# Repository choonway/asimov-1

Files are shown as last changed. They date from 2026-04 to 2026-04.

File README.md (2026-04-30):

# Asimov v1: Open-Source Humanoid Robot




Asimov is an open-source humanoid robot that you can build, train and customize.

Asimov v1
<p align="center">
  <a href="https://asimov.inc">Website</a> ·
  <a href="https://manual.asimov.inc">Manual</a> ·
  <a href="https://asimov.inc/diy-kit">DIY Kit</a> ·
  <a href="https://static.asimov.inc/asimov/v1/asimov-v1-20260420.html">3D Model</a> ·
  <a href="https://discord.gg/HzDfGN7kUw">Discord</a> ·
  <a href="https://x.com/asimovinc">X</a> ·
  <a href="https://forum.menlo.ai">Forum</a>
</p>

Asimov v1 is a 1.2 m, 35 kg biped with 25 actuated degrees of freedom. This repository contains the mechanical CAD, electrical CAD, simulation model, and onboard software to build, simulate, and customize Asimov v1.

---

## Specifications

| Spec | Value |
|---|---|
| Height | 1.2 m |
| Weight | 35 kg |
| Degrees of Freedom | 25 actuated + 2 passive |
| Legs | 6 DOF x 2 + toe x 2 |
| Arms | 5 DOF x 2 (shoulder pitch/roll/yaw, elbow, wrist yaw) |
| Torso | 1 DOF waist yaw, 10 W 4 ohm speaker, 6 DOF IMU |
| Head | 2 DOF neck (neck yaw, neck pitch), Quad microphone array, 2MP monocular camera |
| CAN Bus | 5 @ 1Mbps + 1 @ 500kbps |
| Onboard Compute | Raspberry Pi 5 (media + network) + Radxa CM5 (motion control) |
| Structural Materials | 7075 aluminium, MJF PA12 nylon |

| Activity | Load |
|---|---|
| Squat | 5 kg |
| Bicep curl | 15 kg each arm |
| Lateral raise | 18 kg each arm |

---

## Build your own Asimov

> [!TIP]
> **Option 1: DIY Kit:** Everything you need to build Asimov v1, unassembled. $499 deposit to reserve. $15,000 target price. Ships summer 2026. [Pre-order →](https://asimov.inc/diy-kit)

> [!NOTE]
> **Option 2: Self-source:** Pull the [BOM](https://manual.asimov.inc/v1/bom) and fabricate everything yourself. [Assembly Manual →](https://manual.asimov.inc)

### DIY Kit

| Category | Included | Not Included |
|---|---|---|
| Hardware | All BOM components (unassembled), power supply & cabling, spare parts | Tools, hands |
| Compute | RPi edge board, motion control board, network board, power distribution board | 4G/5G modules |
| Sensors | Monocular camera, IMUs, mic, speaker, motor joint states | Lidar, 360 cam |
| Safety | Wireless E-Stop, safety guidelines | Battery |
| Docs | Quick start guide, manual, DIY build videos | — |

**[Pre-order the Asimov v1 DIY Kit →](https://asimov.inc/diy-kit)**

### Self-source

Pull the [BOM](https://manual.asimov.inc/v1/bom), source the parts, fabricate what needs fabricating.

**[Assembly Manual →](https://manual.asimov.inc)**

---

## Roadmap

| Status | Item |
|---|---|
| ✅ | Mechanical CAD — 7 subassemblies |
| ✅ | MuJoCo simulation model |
| ✅ | Electrical wiring harness |
| ✅ | Electrical schematics & PCB files |
| 🔜 | Asimov API |
| 🔜 | Locomotion policy |
| 🔜 | Mobile app |

---

## Work with us

- **Build questions?**: Ask in the [forum](https://forum.menlo.ai) or open a [GitHub Issue](https://github.com/asimovinc/asimov-v1/issues) for bugs and contributions.
- **Deploying Asimov?**: [Talk to us →](mailto:bd@menlo.ai)
- **Supply chain partner?**: If you manufacture actuators, structural components, or electronics and want to be part of the Asimov supply chain, reach out.
[bd@menlo.ai](mailto:bd@menlo.ai)

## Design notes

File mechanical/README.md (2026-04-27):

# Mechanical Design

CAD for all 7 Asimov v1 subassemblies. STEP files, CNC aluminium parts, MJF nylon parts, and off-the-shelf hardware.

## Contents

```
mechanical/ASV1/
├── ASIMOV_V1.STEP          Full robot assembly
├── 100/ - 700/             Subassemblies
│   ├── ASV1_NNN.STEP       Subassembly STEP
│   └── FABRICATION/
│       ├── ALU_7075/       CNC-machined aluminium parts
│       ├── MJF_PA12/       3D-printed nylon parts (HP MJF)
│       └── OFF_THE_SHELF/  Standard hardware
└── NamingConvention.png    Part naming reference
```

**[View the full assembly in your browser →](https://static.asimov.inc/asimov/v1/asimov-v1-20260420.html)**

## Naming Convention

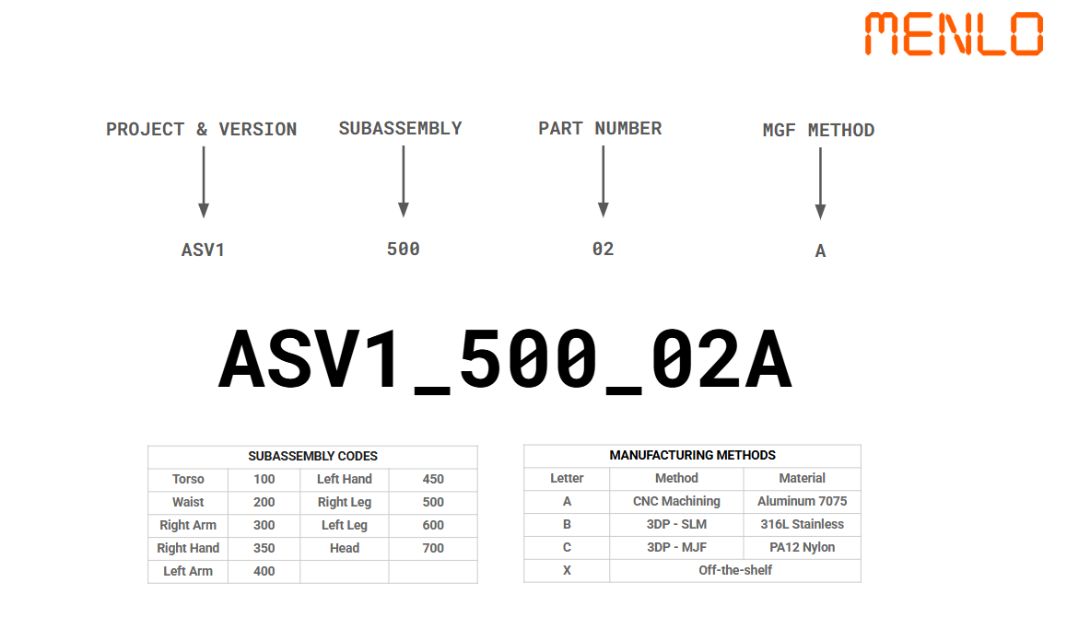
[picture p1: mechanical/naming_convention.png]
Naming Convention


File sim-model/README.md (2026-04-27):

# Simulation Model

MuJoCo model for Asimov v1. 25 actuated joints, 28 link meshes, friction-tuned foot contacts. Built for locomotion policy training and hardware-in-the-loop testing.

## Contents

```
sim-model/
├── xmls/asimov.xml     Full robot model
└── assets/meshes/      28 STL link meshes
```

## Usage

```bash
python3 -m mujoco.viewer --mjcf=sim-model/xmls/asimov.xml
```

Requires [MuJoCo](https://mujoco.org/) 3.x.

## Resources

- [Locomotion Control guide](https://manual.asimov.inc/v1/locomotion) — policy training, control modes, and hardware-in-the-loop setup
- [Asimov API](https://manual.asimov.inc/v1/api) — deploy policies to the real robot
- [Discord](https://discord.gg/HzDfGN7kUw) — questions and discussion

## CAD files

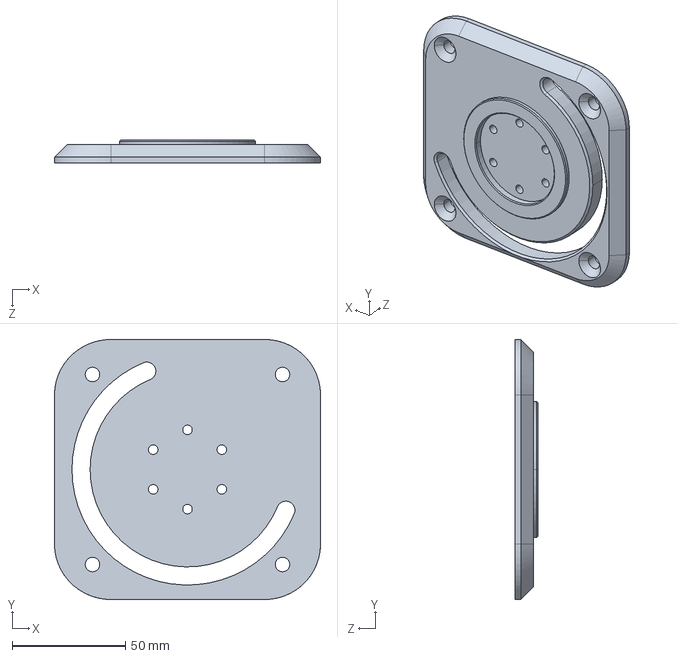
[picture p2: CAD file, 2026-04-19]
mechanical/ASV1/100/FABRICATION/ALU_7075/ASV1_100_02A.STEP
117.4 x 114.8 x 10.0 mm

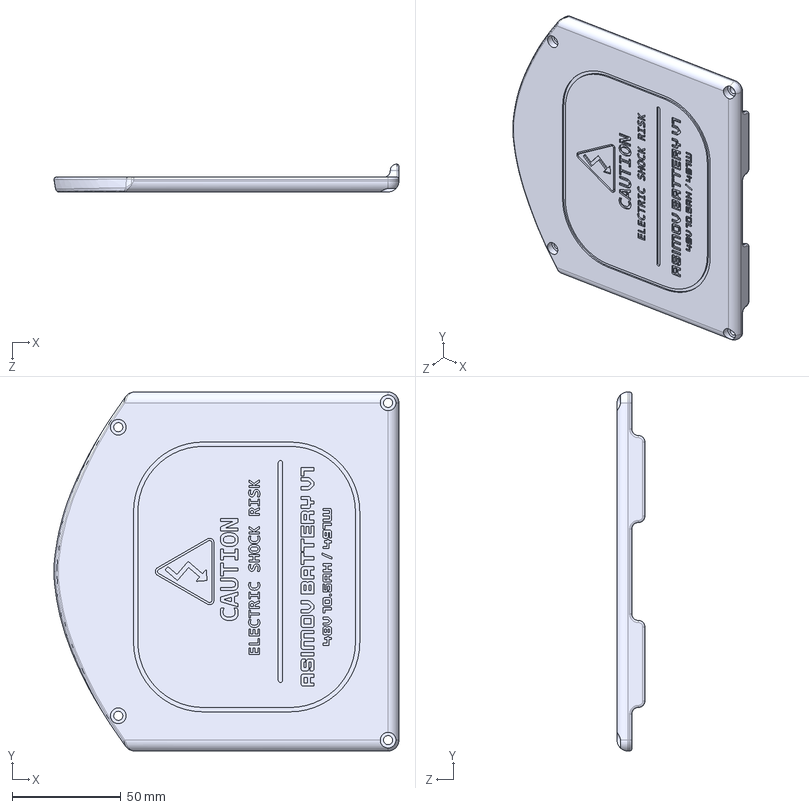
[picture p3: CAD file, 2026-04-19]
mechanical/ASV1/100/FABRICATION/MJF_PA12/ASV1_100_12C.STEP
158.5 x 165.0 x 12.8 mm

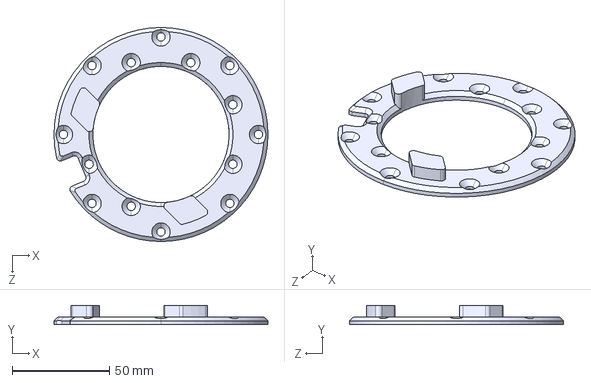
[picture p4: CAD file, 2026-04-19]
mechanical/ASV1/200/FABRICATION/ALU_7075/ASV1_200_02A.STEP
110.0 x 10.0 x 110.0 mm

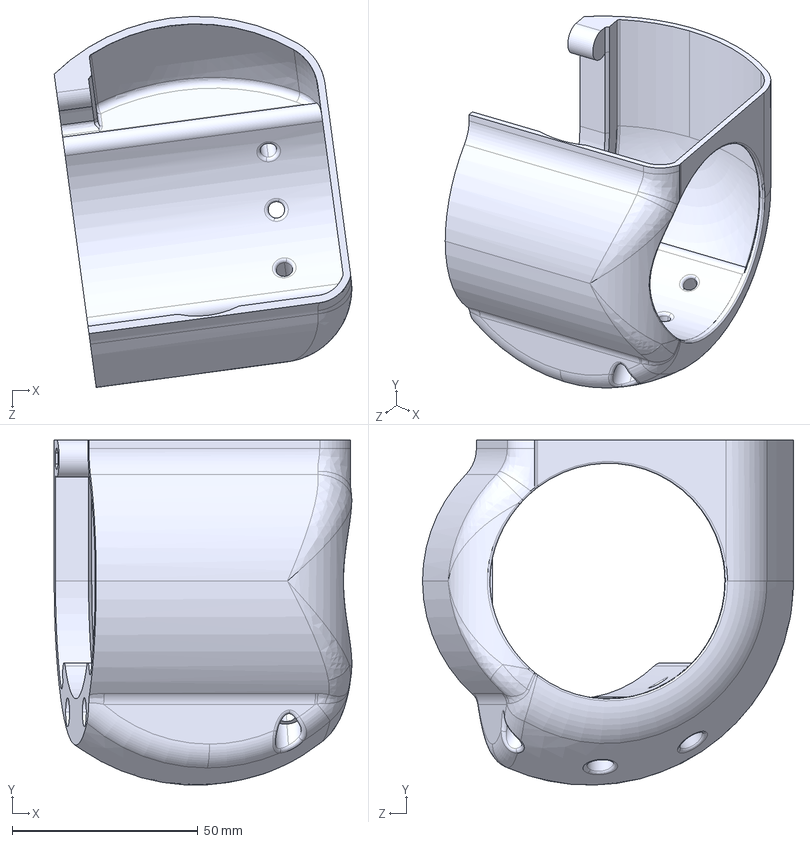
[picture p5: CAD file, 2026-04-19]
mechanical/ASV1/200/FABRICATION/MJF_PA12/ASV1_200_08C.STEP
80.2 x 92.9 x 100.0 mm

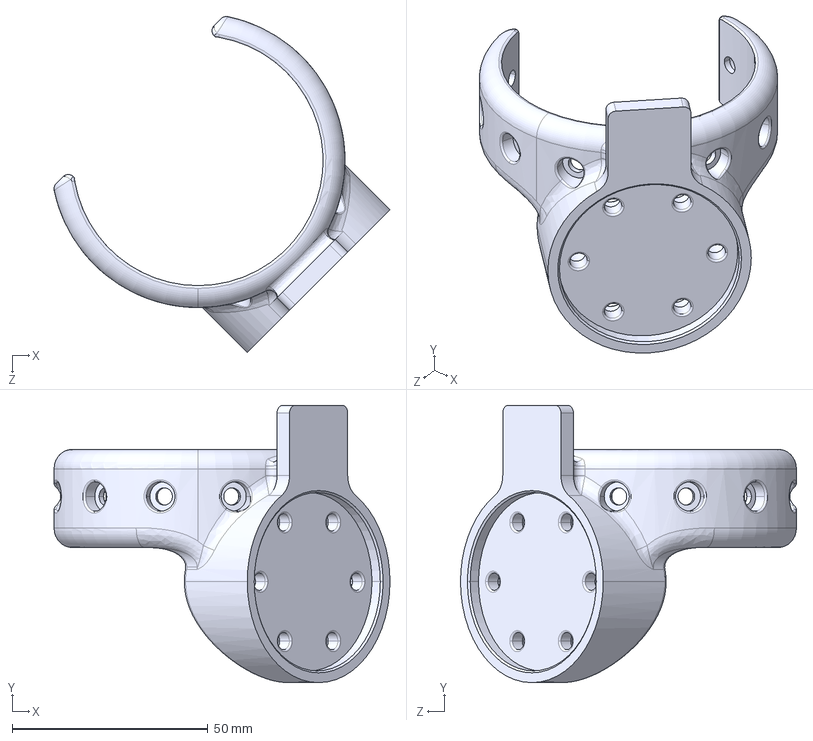
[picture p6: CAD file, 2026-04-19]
mechanical/ASV1/200/FABRICATION/SML_316L/ASV1_200_04B.STEP
85.7 x 70.7 x 85.7 mm

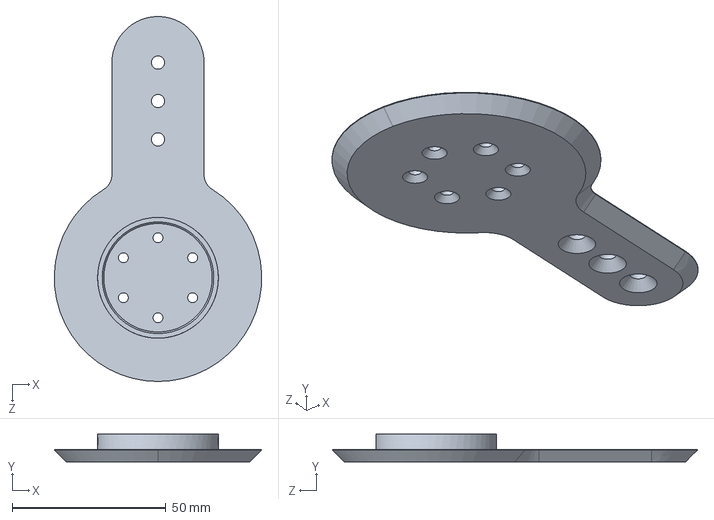
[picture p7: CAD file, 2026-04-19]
mechanical/ASV1/300/FABRICATION/ALU_7075/ASV1_300_10A.STEP
67.5 x 9.00 x 118.8 mm

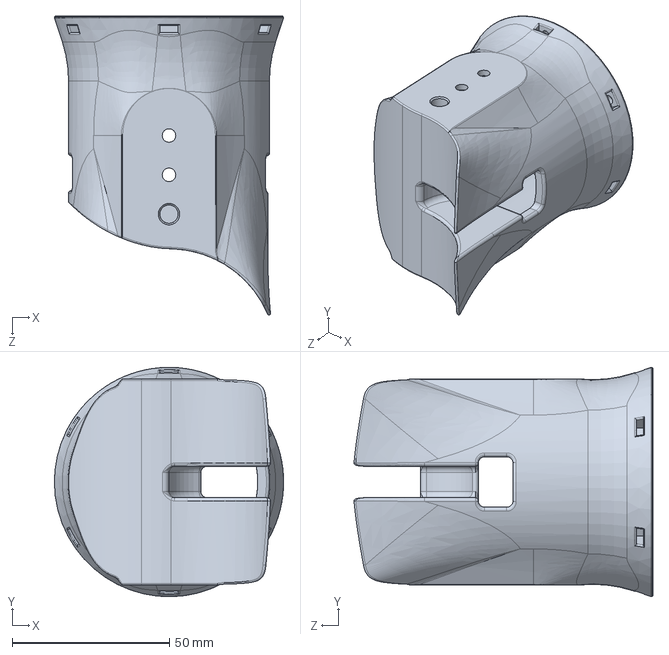
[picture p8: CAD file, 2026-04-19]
mechanical/ASV1/300/FABRICATION/MJF_PA12/ASV1_300_16C.STEP
72.9 x 72.9 x 95.0 mm

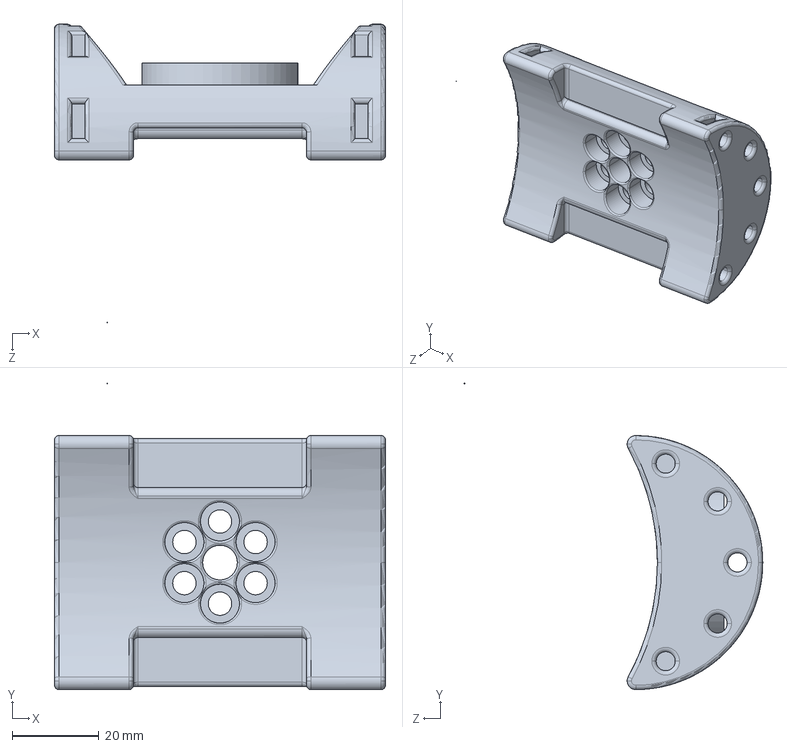
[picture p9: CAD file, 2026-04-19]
mechanical/ASV1/300/FABRICATION/SML_316L/ASV1_300_02B.STEP
76.5 x 70.8 x 69.0 mm

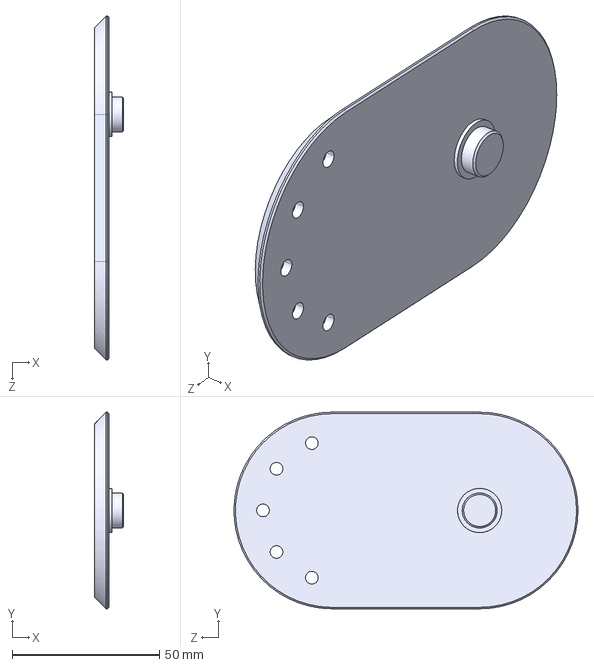
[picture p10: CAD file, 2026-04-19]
mechanical/ASV1/400/FABRICATION/ALU_7075/ASV1_400_04A.STEP
10.0 x 66.7 x 116.7 mm

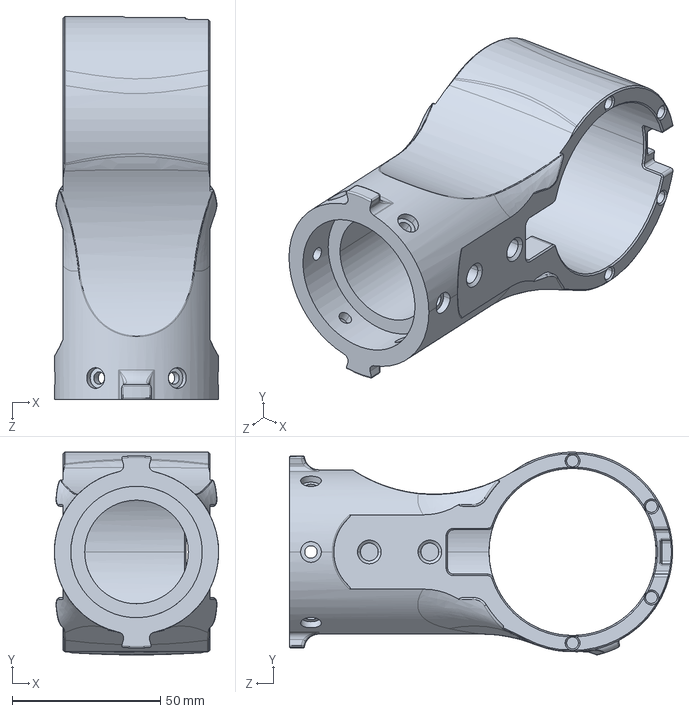
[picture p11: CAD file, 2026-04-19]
mechanical/ASV1/400/FABRICATION/MJF_PA12/ASV1_400_15C.step
55.5 x 68.5 x 129.4 mm

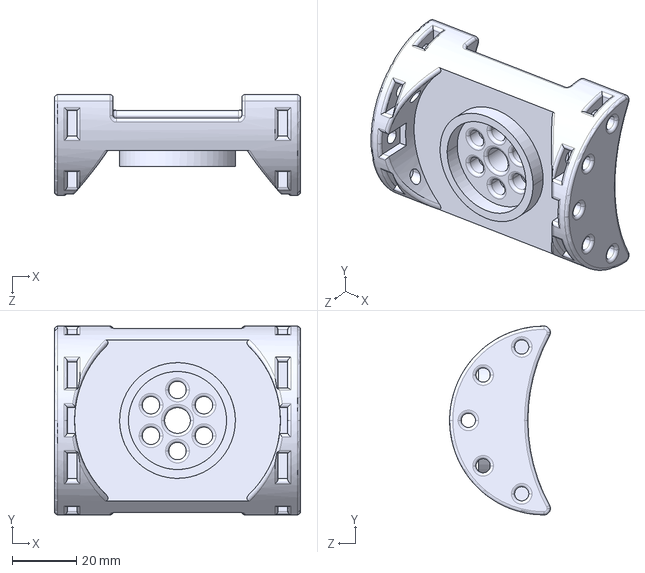
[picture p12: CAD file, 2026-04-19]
mechanical/ASV1/400/FABRICATION/SML_316L/ASV1_400_03B.STEP
76.5 x 58.7 x 31.3 mm

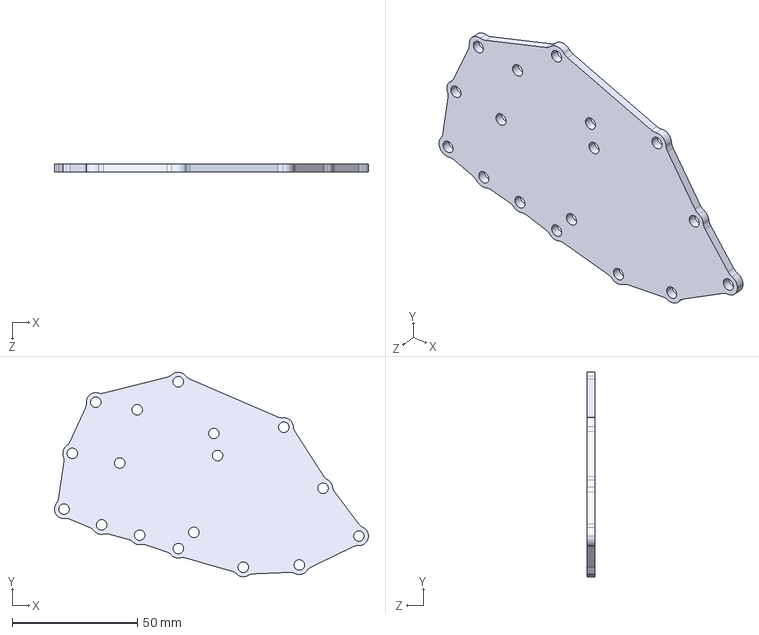
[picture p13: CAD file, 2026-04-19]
mechanical/ASV1/500/FABRICATION/ALU_7075/ASV1_500_36A.STEP
125.1 x 81.5 x 3.00 mm

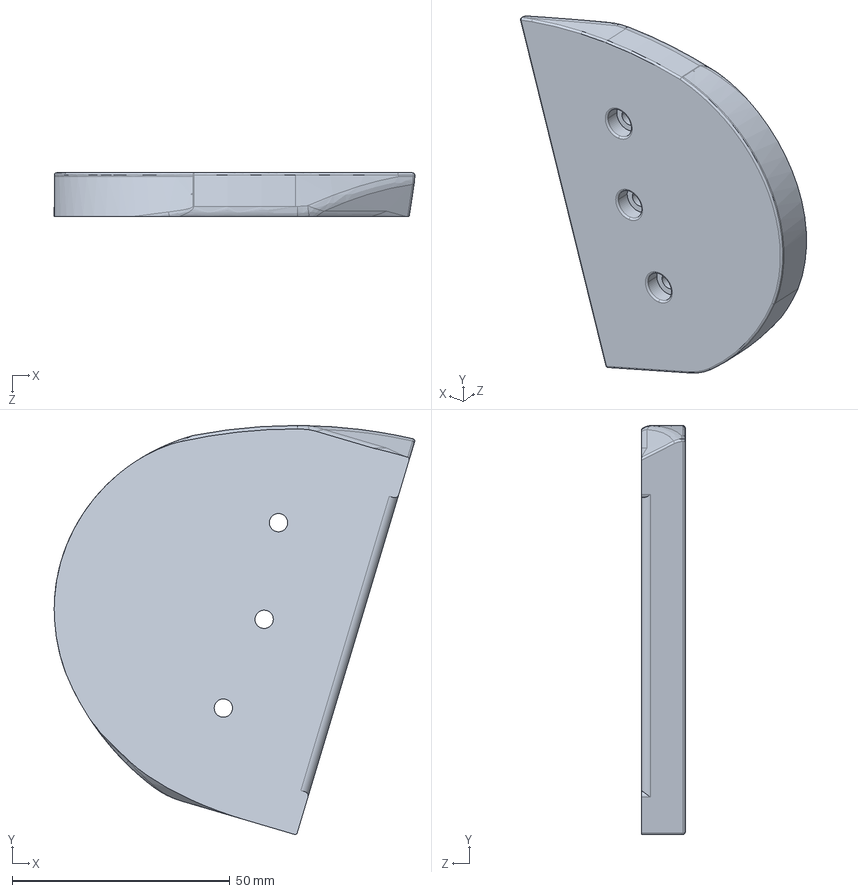
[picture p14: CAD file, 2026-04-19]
mechanical/ASV1/500/FABRICATION/MJF_PA12/ASV1_500_40C.STEP
82.9 x 94.0 x 10.0 mm

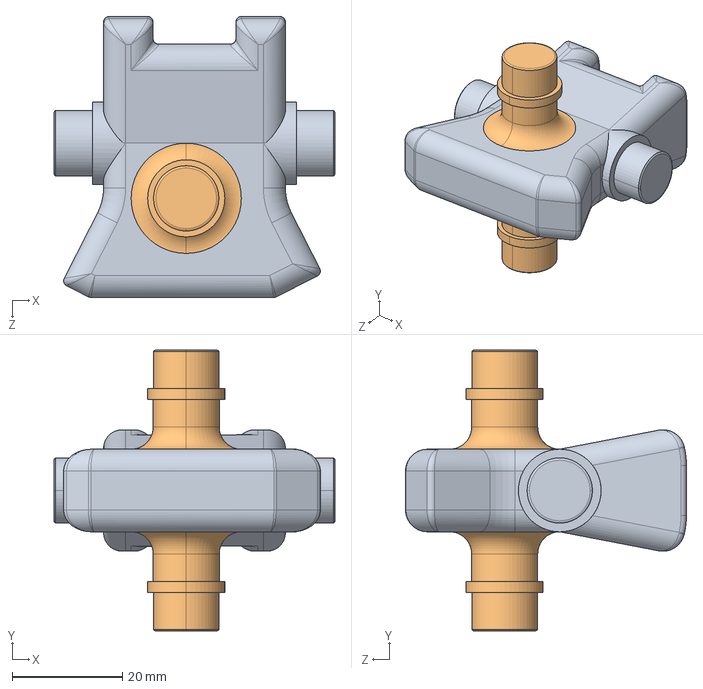
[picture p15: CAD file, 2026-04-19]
mechanical/ASV1/500/FABRICATION/SML_316L/ASV1_500_26B.STEP
51.0 x 51.0 x 51.0 mm

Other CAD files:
mechanical/ASV1/100/ASV1_100.STEP
mechanical/ASV1/600/FABRICATION/ALU_7075/ASV1_600_06A.step.STEP
mechanical/ASV1/600/FABRICATION/MJF_PA12/ASV1_600_14C.step.STEP
mechanical/ASV1/600/FABRICATION/SML_316L/ASV1_600_01B.step.STEP
mechanical/ASV1/100/FABRICATION/ALU_7075/ASV1_100_03A.STEP
mechanical/ASV1/100/FABRICATION/OFF_THE_SHELF/ASV1_100_07X.STEP
mechanical/ASV1/100/FABRICATION/OFF_THE_SHELF/ASV1_100_08X.STEP
mechanical/ASV1/100/FABRICATION/OFF_THE_SHELF/ASV1_100_11X.STEP
mechanical/ASV1/100/FABRICATION/OFF_THE_SHELF/ASV1_100_13X.STEP
mechanical/ASV1/200/FABRICATION/ALU_7075/ASV1_200_03A.STEP
mechanical/ASV1/200/FABRICATION/ALU_7075/ASV1_200_16A.STEP
mechanical/ASV1/200/FABRICATION/MJF_PA12/ASV1_200_01C.STEP
mechanical/ASV1/200/FABRICATION/MJF_PA12/ASV1_200_06C.STEP
mechanical/ASV1/200/FABRICATION/MJF_PA12/ASV1_200_07C.STEP
mechanical/ASV1/200/FABRICATION/MJF_PA12/ASV1_200_09C.STEP
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

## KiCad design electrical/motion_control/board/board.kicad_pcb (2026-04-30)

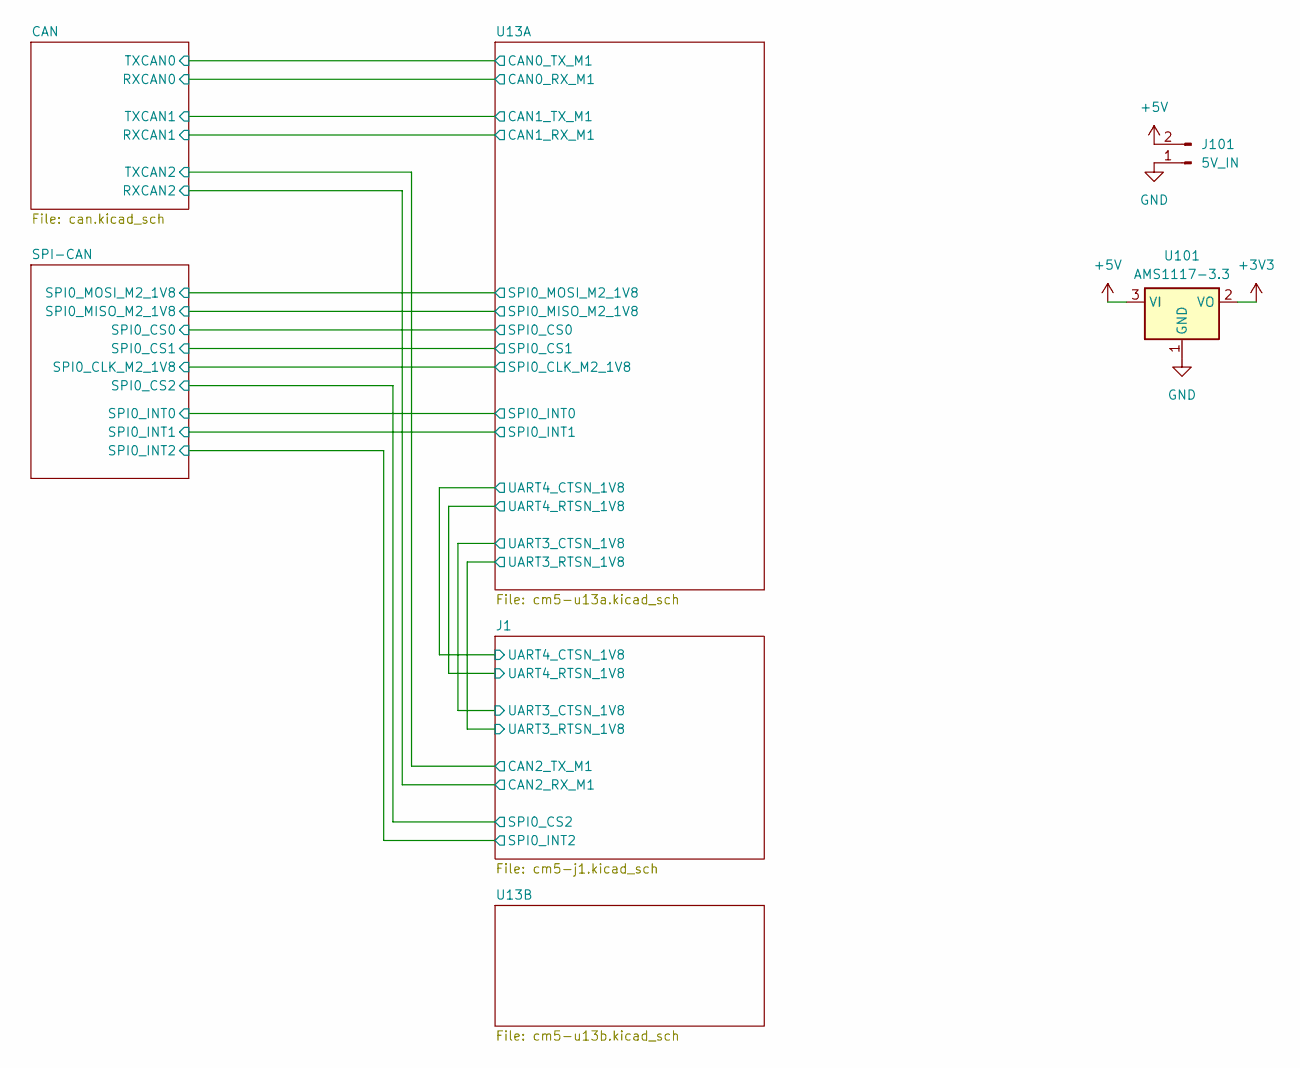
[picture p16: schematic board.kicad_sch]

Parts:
J101: 5V_IN; AMASS_XT30UPB-F_1x02_P5.0mm_Vertical; LCSC C108769
U101: AMS1117-3.3; SOT-223-3_TabPin2; LCSC C6186

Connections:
+3V3: U101.2 (VO); also elsewhere on the board
+5V: J101.2, U101.3 (VI); also elsewhere on the board
GND: J101.1, U101.1 (GND); also elsewhere on the board

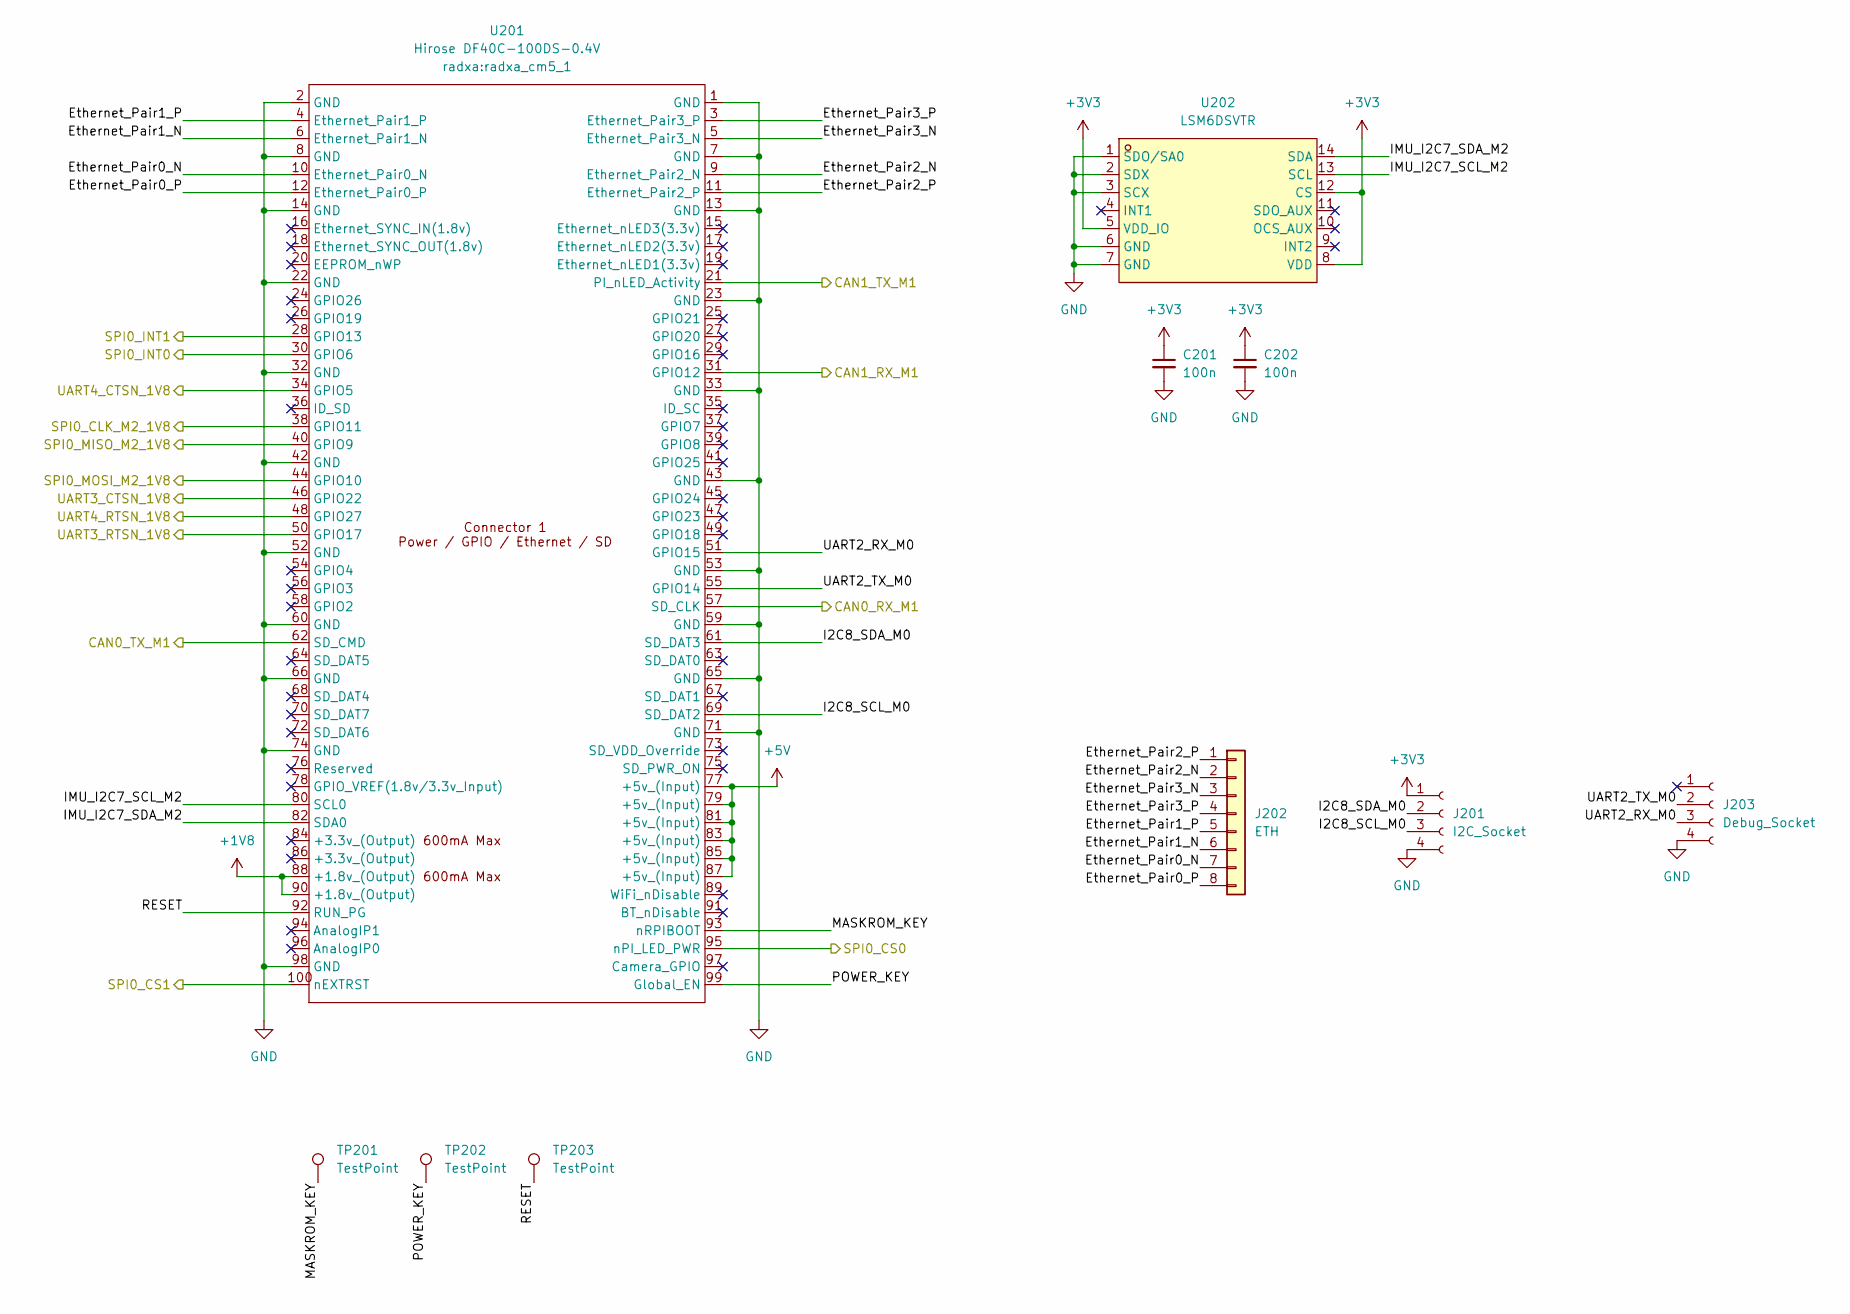
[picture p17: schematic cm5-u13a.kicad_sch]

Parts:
C201, C202: 100n; C_0402_1005Metric; LCSC C77020
J201: I2C_Socket; JST_GH_SM04B-GHS-TB_1x04-1MP_P1.25mm_Horizontal; LCSC C51940118
J202: ETH; JST_GH_BM08B-GHS-TBT_1x08-1MP_P1.25mm_Vertical; LCSC C133062
J203: Debug_Socket; JST_GH_SM04B-GHS-TB_1x04-1MP_P1.25mm_Horizontal; LCSC C51940118
TP201, TP202, TP203: TestPoint; TestPoint_Pad_D1.0mm
U201: Hirose DF40C-100DS-0.4V; radxa_cm5_1; LCSC C597931
U202: LSM6DSVTR; LGA-14_L3.0-W2.5-P0.50-TL; LCSC Part C5267399

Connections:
+1V8: U201.88 (+1.8v_(Output)), U201.90 (+1.8v_(Output)); also elsewhere on the board
+3V3: C201.1, C202.1, J201.1, U202.5 (VDD_IO), U202.8 (VDD), U202.12 (CS); also elsewhere on the board
+5V: U201.77 (+5v_(Input)), U201.79 (+5v_(Input)), U201.81 (+5v_(Input)), U201.83 (+5v_(Input)), U201.85 (+5v_(Input)), U201.87 (+5v_(Input)); also elsewhere on the board
/CAN/RXCAN0: U201.57 (SD_CLK); also elsewhere on the board
/CAN/RXCAN1: U201.31 (GPIO12); also elsewhere on the board
/CAN/TXCAN0: U201.62 (SD_CMD); also elsewhere on the board
/CAN/TXCAN1: U201.21 (PI_nLED_Activity); also elsewhere on the board
/J1/UART3_CTSN_1V8: U201.46 (GPIO22); also elsewhere on the board
/J1/UART3_RTSN_1V8: U201.50 (GPIO17); also elsewhere on the board
/J1/UART4_CTSN_1V8: U201.34 (GPIO5); also elsewhere on the board
/J1/UART4_RTSN_1V8: U201.48 (GPIO27); also elsewhere on the board
/SPI-CAN/SPI0_CLK_M2_1V8: U201.38 (GPIO11); also elsewhere on the board
/SPI-CAN/SPI0_CS0: U201.95 (nPI_LED_PWR); also elsewhere on the board
/SPI-CAN/SPI0_CS1: U201.100 (nEXTRST); also elsewhere on the board
/SPI-CAN/SPI0_INT0: U201.30 (GPIO6); also elsewhere on the board
/SPI-CAN/SPI0_INT1: U201.28 (GPIO13); also elsewhere on the board
/SPI-CAN/SPI0_MISO_M2_1V8: U201.40 (GPIO9); also elsewhere on the board
/SPI-CAN/SPI0_MOSI_M2_1V8: U201.44 (GPIO10); also elsewhere on the board
/U13A/Ethernet_Pair0_N: J202.7, U201.10 (Ethernet_Pair0_N)
/U13A/Ethernet_Pair0_P: J202.8, U201.12 (Ethernet_Pair0_P)
/U13A/Ethernet_Pair1_N: J202.6, U201.6 (Ethernet_Pair1_N)
/U13A/Ethernet_Pair1_P: J202.5, U201.4 (Ethernet_Pair1_P)
/U13A/Ethernet_Pair2_N: J202.2, U201.9 (Ethernet_Pair2_N)
/U13A/Ethernet_Pair2_P: J202.1, U201.11 (Ethernet_Pair2_P)
/U13A/Ethernet_Pair3_N: J202.3, U201.5 (Ethernet_Pair3_N)
/U13A/Ethernet_Pair3_P: J202.4, U201.3 (Ethernet_Pair3_P)
/U13A/I2C8_SCL_M0: J201.3, U201.69 (SD_DAT2)
/U13A/I2C8_SDA_M0: J201.2, U201.61 (SD_DAT3)
/U13A/IMU_I2C7_SCL_M2: U201.80 (SCL0), U202.13 (SCL)
/U13A/IMU_I2C7_SDA_M2: U201.82 (SDA0), U202.14 (SDA)
/U13A/MASKROM_KEY: TP201.1, U201.93 (nRPIBOOT)
/U13A/POWER_KEY: TP202.1, U201.99 (Global_EN)
/U13A/RESET: TP203.1, U201.92 (RUN_PG)
/U13A/UART2_RX_M0: J203.3, U201.51 (GPIO15)
/U13A/UART2_TX_M0: J203.2, U201.55 (GPIO14)
GND: C201.2, C202.2, J201.4, J203.4, U201.1 (GND), U201.2 (GND), U201.7 (GND), U201.8 (GND), U201.13 (GND), U201.14 (GND), U201.22 (GND), U201.23 (GND), U201.32 (GND), U201.33 (GND), U201.42 (GND), U201.43 (GND), U201.52 (GND), U201.53 (GND), U201.59 (GND), U201.60 (GND), U201.65 (GND), U201.66 (GND), U201.71 (GND), U201.74 (GND), U201.98 (GND), U202.1 (SDO/SA0), U202.2 (SDX), U202.3 (SCX), U202.6 (GND), U202.7 (GND); also elsewhere on the board

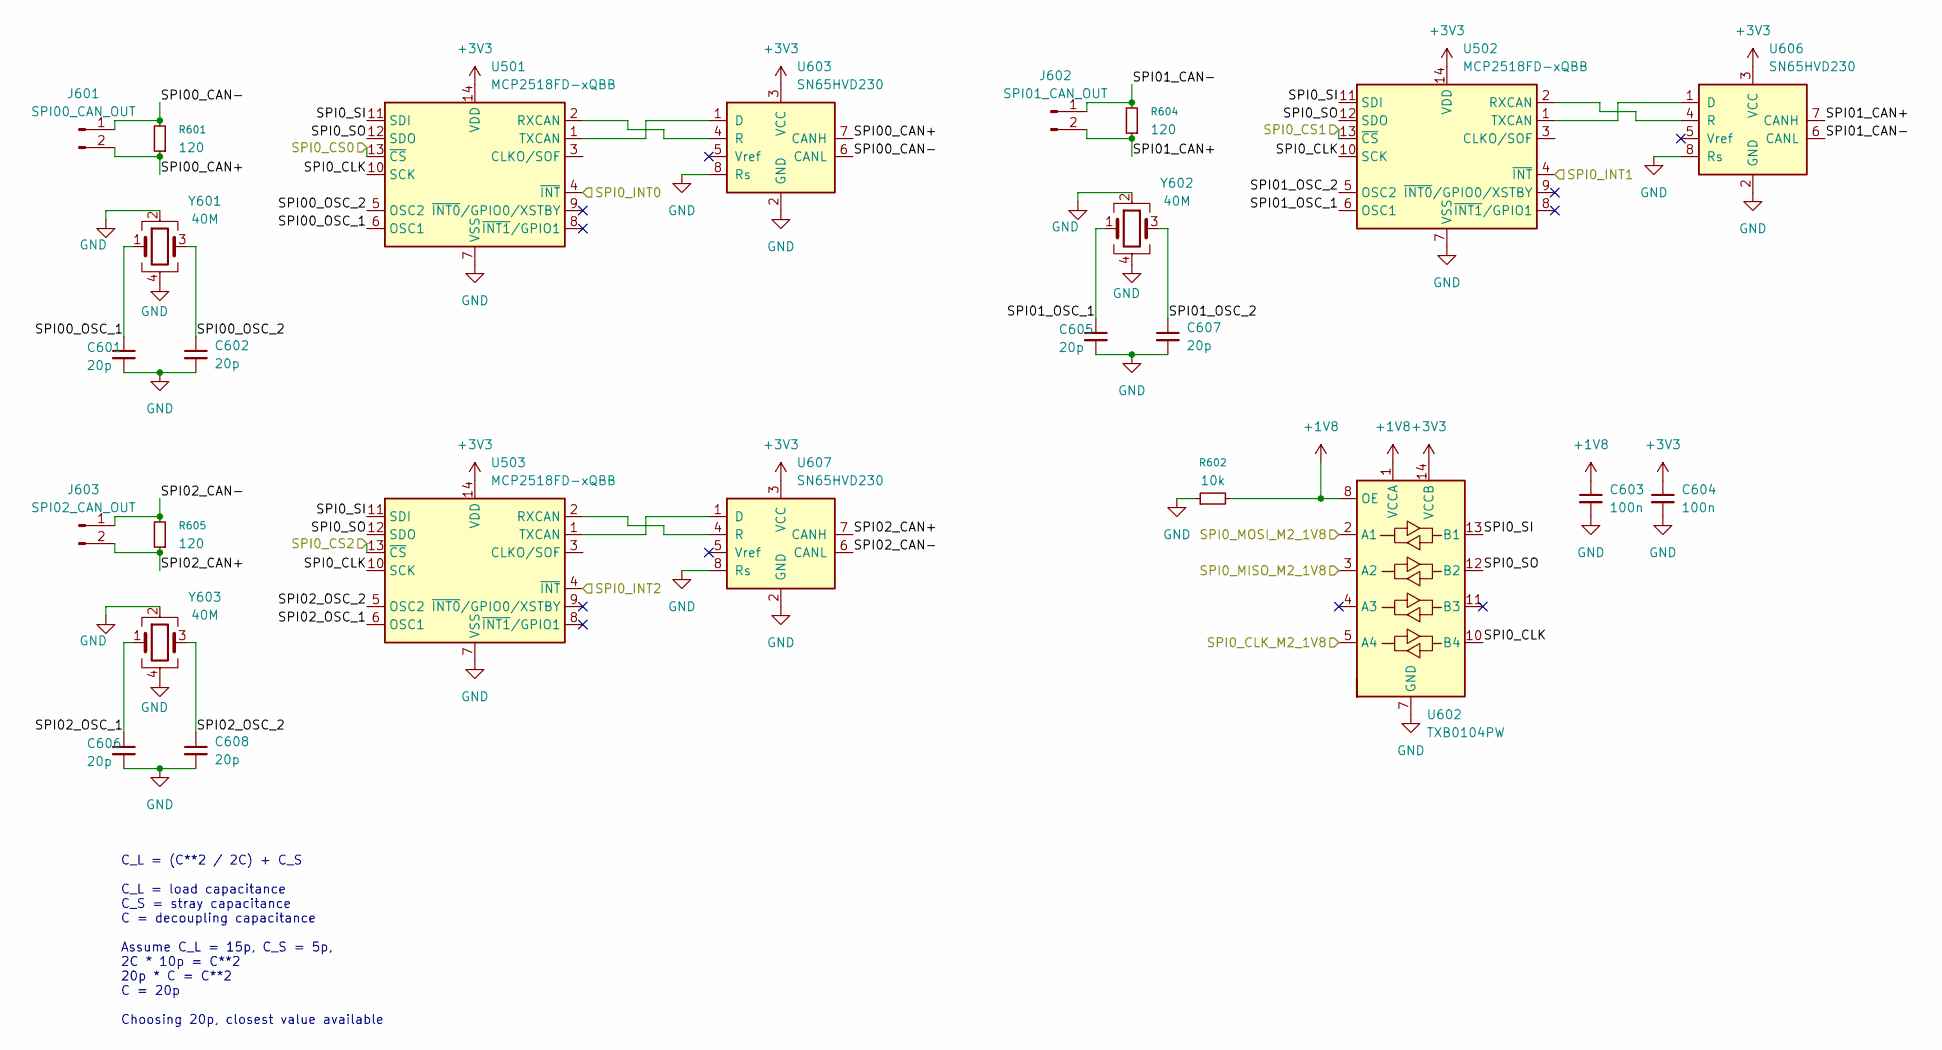
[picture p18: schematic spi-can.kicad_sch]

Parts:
C601, C602, C605, C606, C607, C608: 20p; C_0603_1608Metric; LCSC C165732
C603, C604: 100n; C_0402_1005Metric; LCSC C77020
J601: SPI00_CAN_OUT; JST_GH_SM02B-GHS-TB_1x02-1MP_P1.25mm_Horizontal; LCSC C189893
J602: SPI01_CAN_OUT; JST_GH_SM02B-GHS-TB_1x02-1MP_P1.25mm_Horizontal; LCSC C189893
J603: SPI02_CAN_OUT; JST_GH_SM02B-GHS-TB_1x02-1MP_P1.25mm_Horizontal; LCSC C189893
R601, R604, R605: 120; R_0402_1005Metric; LCSC C114758
R602: 10k; R_0402_1005Metric; LCSC C190095
U501, U502, U503: MCP2518FD-xQBB; SOIC-14_3.9x8.7mm_P1.27mm; LCSC C626758
U602: TXB0104PW; TSSOP-14_4.4x5mm_P0.65mm; LCSC C60708
U603, U606, U607: SN65HVD230; SOIC-8_3.9x4.9mm_P1.27mm; LCSC C12084
Y601, Y602, Y603: 40M; Crystal_SMD_3225-4Pin_3.2x2.5mm; LCSC C5444549

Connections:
+1V8: C603.1, R602.2, U602.1 (VCCA), U602.8 (OE); also elsewhere on the board
+3V3: C604.1, U501.14 (VDD), U502.14 (VDD), U503.14 (VDD), U602.14 (VCCB), U603.3 (VCC), U606.3 (VCC), U607.3 (VCC); also elsewhere on the board
/J1/SPI0_CS2: U503.13 (~CS); also elsewhere on the board
/J1/SPI0_INT2: U503.4 (~INT); also elsewhere on the board
/SPI-CAN/SPI00_CAN+: J601.2, R601.1, U603.7 (CANH)
/SPI-CAN/SPI00_CAN-: J601.1, R601.2, U603.6 (CANL)
/SPI-CAN/SPI0_CLK: U501.10 (SCK), U502.10 (SCK), U503.10 (SCK), U602.10 (B4)
/SPI-CAN/SPI0_CLK_M2_1V8: U602.5 (A4); also elsewhere on the board
/SPI-CAN/SPI0_CS0: U501.13 (~CS); also elsewhere on the board
/SPI-CAN/SPI0_CS1: U502.13 (~CS); also elsewhere on the board
/SPI-CAN/SPI0_INT0: U501.4 (~INT); also elsewhere on the board
/SPI-CAN/SPI0_INT1: U502.4 (~INT); also elsewhere on the board
/SPI-CAN/SPI0_MISO_M2_1V8: U602.3 (A2); also elsewhere on the board
/SPI-CAN/SPI0_MOSI_M2_1V8: U602.2 (A1); also elsewhere on the board
/SPI-CAN/SPI00_OSC_1: C601.1, U501.6 (OSC1), Y601.1
/SPI-CAN/SPI00_OSC_2: C602.1, U501.5 (OSC2), Y601.3
/SPI-CAN/SPI0_SI: U501.11 (SDI), U502.11 (SDI), U503.11 (SDI), U602.13 (B1)
/SPI-CAN/SPI0_SO: U501.12 (SDO), U502.12 (SDO), U503.12 (SDO), U602.12 (B2)
/SPI-CAN/SPI01_CAN+: J602.2, R604.1, U606.7 (CANH)
/SPI-CAN/SPI01_CAN-: J602.1, R604.2, U606.6 (CANL)
/SPI-CAN/SPI01_OSC_1: C605.1, U502.6 (OSC1), Y602.1
/SPI-CAN/SPI01_OSC_2: C607.1, U502.5 (OSC2), Y602.3
/SPI-CAN/SPI02_CAN+: J603.2, R605.1, U607.7 (CANH)
/SPI-CAN/SPI02_CAN-: J603.1, R605.2, U607.6 (CANL)
/SPI-CAN/SPI02_OSC_1: C606.1, U503.6 (OSC1), Y603.1
/SPI-CAN/SPI02_OSC_2: C608.1, U503.5 (OSC2), Y603.3
GND: C601.2, C602.2, C603.2, C604.2, C605.2, C606.2, C607.2, C608.2, R602.1, U501.7 (VSS), U501.15 (VSS), U502.7 (VSS), U502.15 (VSS), U503.7 (VSS), U503.15 (VSS), U602.7 (GND), U603.2 (GND), U603.8 (Rs), U606.2 (GND), U606.8 (Rs), U607.2 (GND), U607.8 (Rs), Y601.2, Y601.4, Y602.2, Y602.4, Y603.2, Y603.4; also elsewhere on the board
unnamed: U501.2 (RXCAN), U603.4 (R)
unnamed: U501.1 (TXCAN), U603.1 (D)
unnamed: U502.2 (RXCAN), U606.4 (R)
unnamed: U502.1 (TXCAN), U606.1 (D)
unnamed: U503.2 (RXCAN), U607.4 (R)
unnamed: U503.1 (TXCAN), U607.1 (D)

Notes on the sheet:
C_L = (C**2 / 2C) + C_S C_L = load capacitance C_S = stray capacitance C = decoupling capacitance Assume C_L = 15p, C_S = 5p, 2C * 10p = C**2 20p * C = C**2 C = 20p Choosing 20p, closest value available

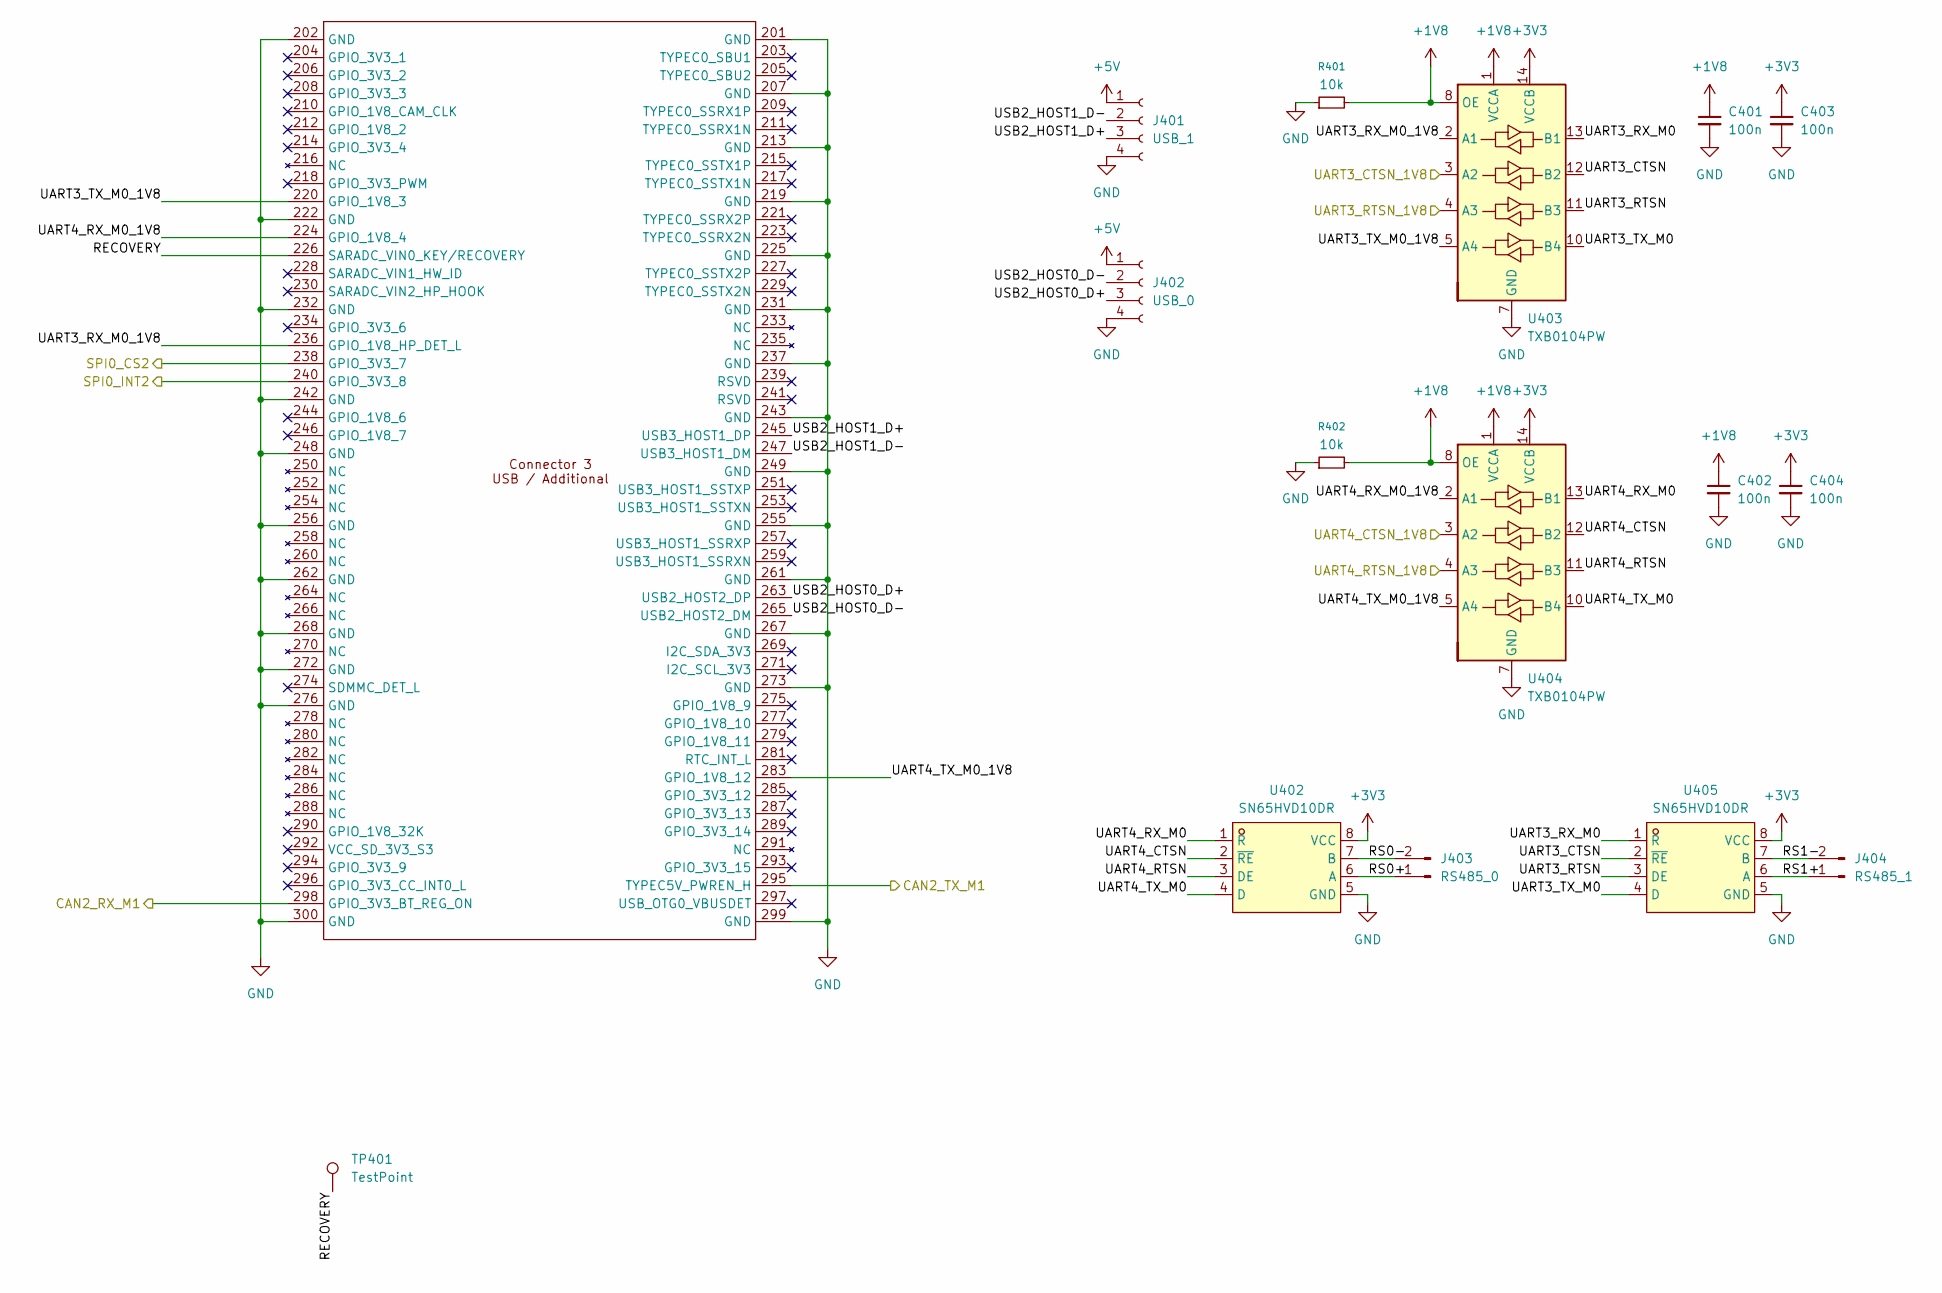
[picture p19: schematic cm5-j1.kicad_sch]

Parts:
C401, C402, C403, C404: 100n; C_0402_1005Metric; LCSC C77020
J401: USB_1; JST_GH_SM04B-GHS-TB_1x04-1MP_P1.25mm_Horizontal; LCSC C51940118
J402: USB_0; JST_GH_SM04B-GHS-TB_1x04-1MP_P1.25mm_Horizontal; LCSC C51940118
J403: RS485_0; JST_GH_SM02B-GHS-TB_1x02-1MP_P1.25mm_Horizontal; LCSC C189893
J404: RS485_1; JST_GH_SM02B-GHS-TB_1x02-1MP_P1.25mm_Horizontal; LCSC C189893
R401, R402: 10k; R_0402_1005Metric; LCSC C190095
TP401: TestPoint; TestPoint_Pad_D1.0mm
U401: Hirose DF40C-100DS-0.4V; radxa_cm5_3; LCSC C597931
U402, U405: SN65HVD10DR; SOIC-8_L4.9-W3.9-P1.27-LS6.0-BL; LCSC Part C148982
U403, U404: TXB0104PW; TSSOP-14_4.4x5mm_P0.65mm; LCSC C60708

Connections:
+1V8: C401.1, C402.1, R401.2, R402.2, U403.1 (VCCA), U403.8 (OE), U404.1 (VCCA), U404.8 (OE); also elsewhere on the board
+3V3: C403.1, C404.1, U402.8 (VCC), U403.14 (VCCB), U404.14 (VCCB), U405.8 (VCC); also elsewhere on the board
+5V: J401.1, J402.1; also elsewhere on the board
/CAN/RXCAN2: U401.298 (GPIO_3V3_BT_REG_ON); also elsewhere on the board
/CAN/TXCAN2: U401.295 (TYPEC5V_PWREN_H); also elsewhere on the board
/J1/RECOVERY: TP401.1, U401.226 (SARADC_VIN0_KEY/RECOVERY)
/J1/RS0+: J403.1, U402.6 (A)
/J1/RS0-: J403.2, U402.7 (B)
/J1/RS1+: J404.1, U405.6 (A)
/J1/RS1-: J404.2, U405.7 (B)
/J1/SPI0_CS2: U401.238 (GPIO_3V3_7); also elsewhere on the board
/J1/SPI0_INT2: U401.240 (GPIO_3V3_8); also elsewhere on the board
/J1/UART3_CTSN: U403.12 (B2), U405.2 (~RE)
/J1/UART3_CTSN_1V8: U403.3 (A2); also elsewhere on the board
/J1/UART3_RTSN: U403.11 (B3), U405.3 (DE)
/J1/UART3_RTSN_1V8: U403.4 (A3); also elsewhere on the board
/J1/UART3_RX_M0: U403.13 (B1), U405.1 (R)
/J1/UART3_RX_M0_1V8: U401.236 (GPIO_1V8_HP_DET_L), U403.2 (A1)
/J1/UART3_TX_M0: U403.10 (B4), U405.4 (D)
/J1/UART3_TX_M0_1V8: U401.220 (GPIO_1V8_3), U403.5 (A4)
/J1/UART4_CTSN: U402.2 (~RE), U404.12 (B2)
/J1/UART4_CTSN_1V8: U404.3 (A2); also elsewhere on the board
/J1/UART4_RTSN: U402.3 (DE), U404.11 (B3)
/J1/UART4_RTSN_1V8: U404.4 (A3); also elsewhere on the board
/J1/UART4_RX_M0: U402.1 (R), U404.13 (B1)
/J1/UART4_RX_M0_1V8: U401.224 (GPIO_1V8_4), U404.2 (A1)
/J1/UART4_TX_M0: U402.4 (D), U404.10 (B4)
/J1/UART4_TX_M0_1V8: U401.283 (GPIO_1V8_12), U404.5 (A4)
/J1/USB2_HOST0_D+: J402.3, U401.263 (USB2_HOST2_DP)
/J1/USB2_HOST0_D-: J402.2, U401.265 (USB2_HOST2_DM)
/J1/USB2_HOST1_D+: J401.3, U401.245 (USB3_HOST1_DP)
/J1/USB2_HOST1_D-: J401.2, U401.247 (USB3_HOST1_DM)
GND: C401.2, C402.2, C403.2, C404.2, J401.4, J402.4, R401.1, R402.1, U401.201 (GND), U401.202 (GND), U401.207 (GND), U401.213 (GND), U401.219 (GND), U401.222 (GND), U401.225 (GND), U401.231 (GND), U401.232 (GND), U401.237 (GND), U401.242 (GND), U401.243 (GND), U401.248 (GND), U401.249 (GND), U401.255 (GND), U401.256 (GND), U401.261 (GND), U401.262 (GND), U401.267 (GND), U401.268 (GND), U401.272 (GND), U401.273 (GND), U401.276 (GND), U401.299 (GND), U401.300 (GND), U402.5 (GND), U403.7 (GND), U404.7 (GND), U405.5 (GND); also elsewhere on the board

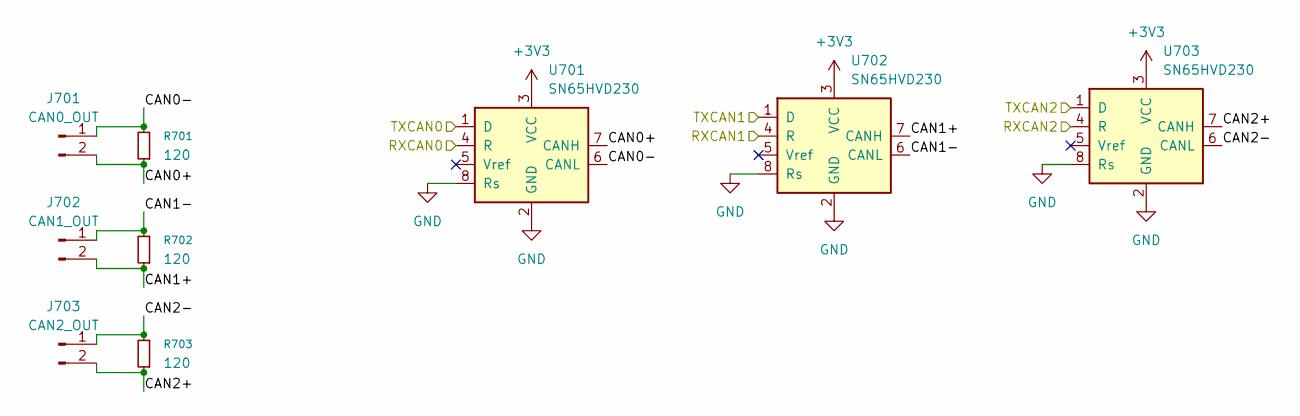
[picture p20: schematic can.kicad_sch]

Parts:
J701: CAN0_OUT; JST_GH_SM02B-GHS-TB_1x02-1MP_P1.25mm_Horizontal; LCSC C189893
J702: CAN1_OUT; JST_GH_SM02B-GHS-TB_1x02-1MP_P1.25mm_Horizontal; LCSC C189893
J703: CAN2_OUT; JST_GH_SM02B-GHS-TB_1x02-1MP_P1.25mm_Horizontal; LCSC C189893
R701, R702, R703: 120; R_0402_1005Metric; LCSC C114758
U701, U702, U703: SN65HVD230; SOIC-8_3.9x4.9mm_P1.27mm; LCSC C12084

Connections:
+3V3: U701.3 (VCC), U702.3 (VCC), U703.3 (VCC); also elsewhere on the board
/CAN/CAN0+: J701.2, R701.1, U701.7 (CANH)
/CAN/CAN0-: J701.1, R701.2, U701.6 (CANL)
/CAN/CAN1+: J702.2, R702.1, U702.7 (CANH)
/CAN/CAN1-: J702.1, R702.2, U702.6 (CANL)
/CAN/CAN2+: J703.2, R703.1, U703.7 (CANH)
/CAN/CAN2-: J703.1, R703.2, U703.6 (CANL)
/CAN/RXCAN0: U701.4 (R); also elsewhere on the board
/CAN/RXCAN1: U702.4 (R); also elsewhere on the board
/CAN/RXCAN2: U703.4 (R); also elsewhere on the board
/CAN/TXCAN0: U701.1 (D); also elsewhere on the board
/CAN/TXCAN1: U702.1 (D); also elsewhere on the board
/CAN/TXCAN2: U703.1 (D); also elsewhere on the board
GND: U701.2 (GND), U701.8 (Rs), U702.2 (GND), U702.8 (Rs), U703.2 (GND), U703.8 (Rs); also elsewhere on the board

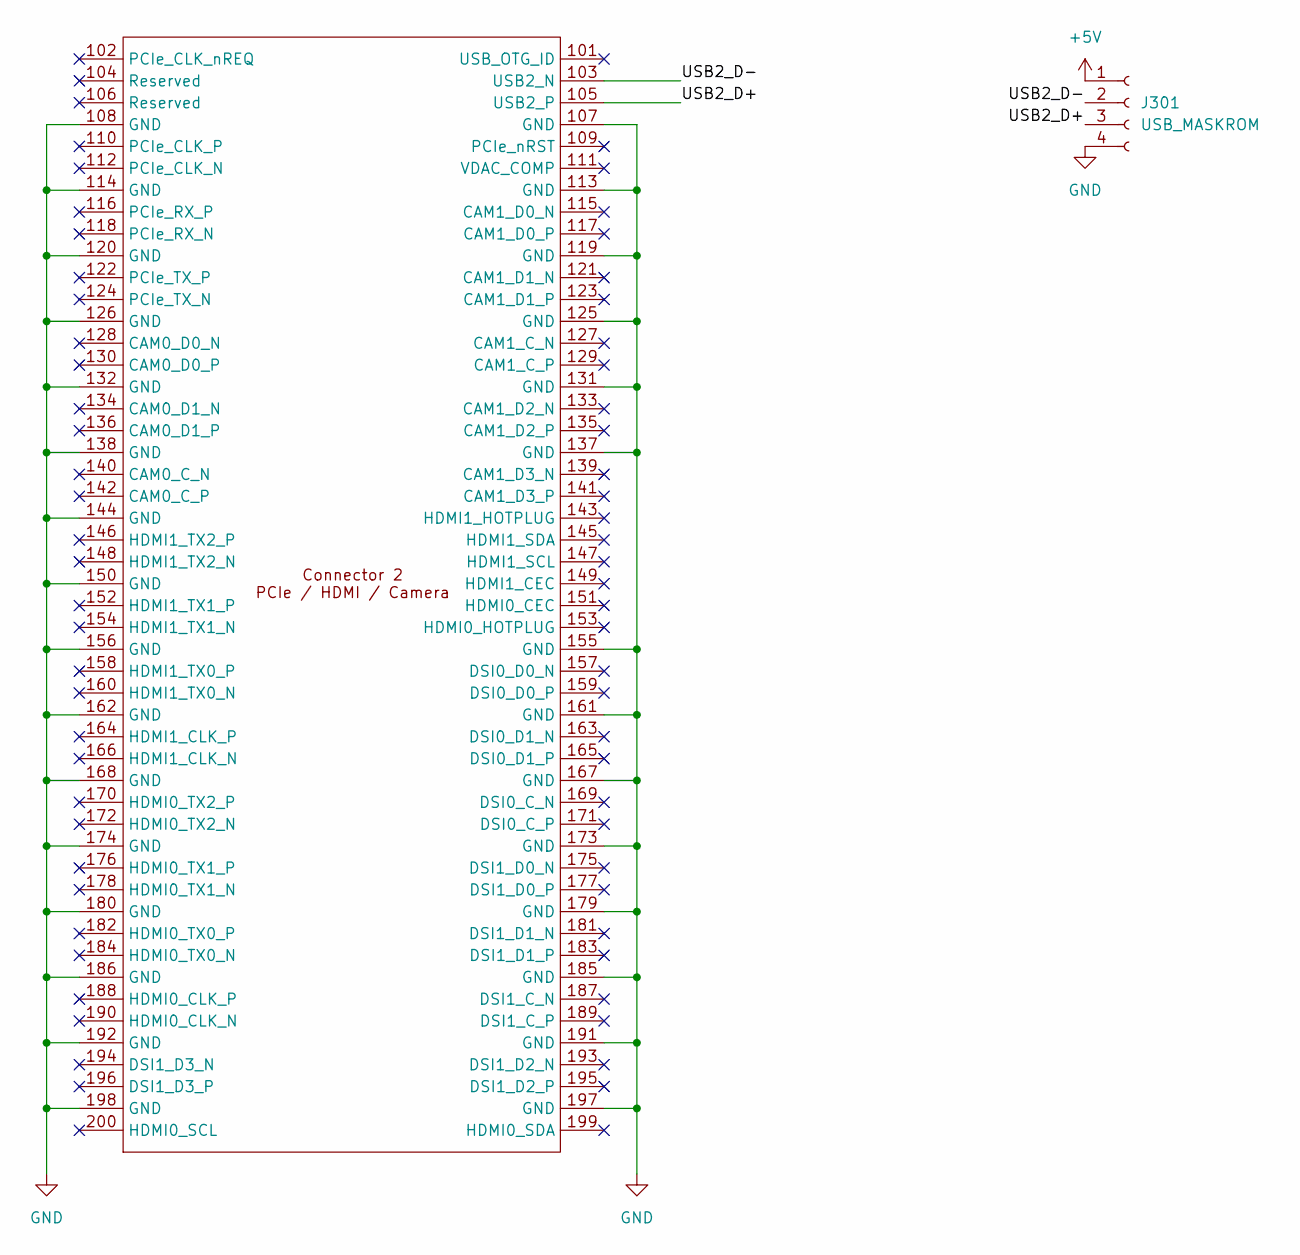
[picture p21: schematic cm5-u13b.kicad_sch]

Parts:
J301: USB_MASKROM; JST_GH_SM04B-GHS-TB_1x04-1MP_P1.25mm_Horizontal; LCSC C51940118
U301: Hirose DF40C-100DS-0.4V; radxa_cm5_2; LCSC C597931

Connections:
+5V: J301.1; also elsewhere on the board
/U13B/USB2_D+: J301.3, U301.105 (USB2_P)
/U13B/USB2_D-: J301.2, U301.103 (USB2_N)
GND: J301.4, U301.107 (GND), U301.108 (GND), U301.113 (GND), U301.114 (GND), U301.119 (GND), U301.120 (GND), U301.125 (GND), U301.126 (GND), U301.131 (GND), U301.132 (GND), U301.137 (GND), U301.138 (GND), U301.144 (GND), U301.150 (GND), U301.155 (GND), U301.156 (GND), U301.161 (GND), U301.162 (GND), U301.167 (GND), U301.168 (GND), U301.173 (GND), U301.174 (GND), U301.179 (GND), U301.180 (GND), U301.185 (GND), U301.186 (GND), U301.191 (GND), U301.192 (GND), U301.197 (GND), U301.198 (GND); also elsewhere on the board

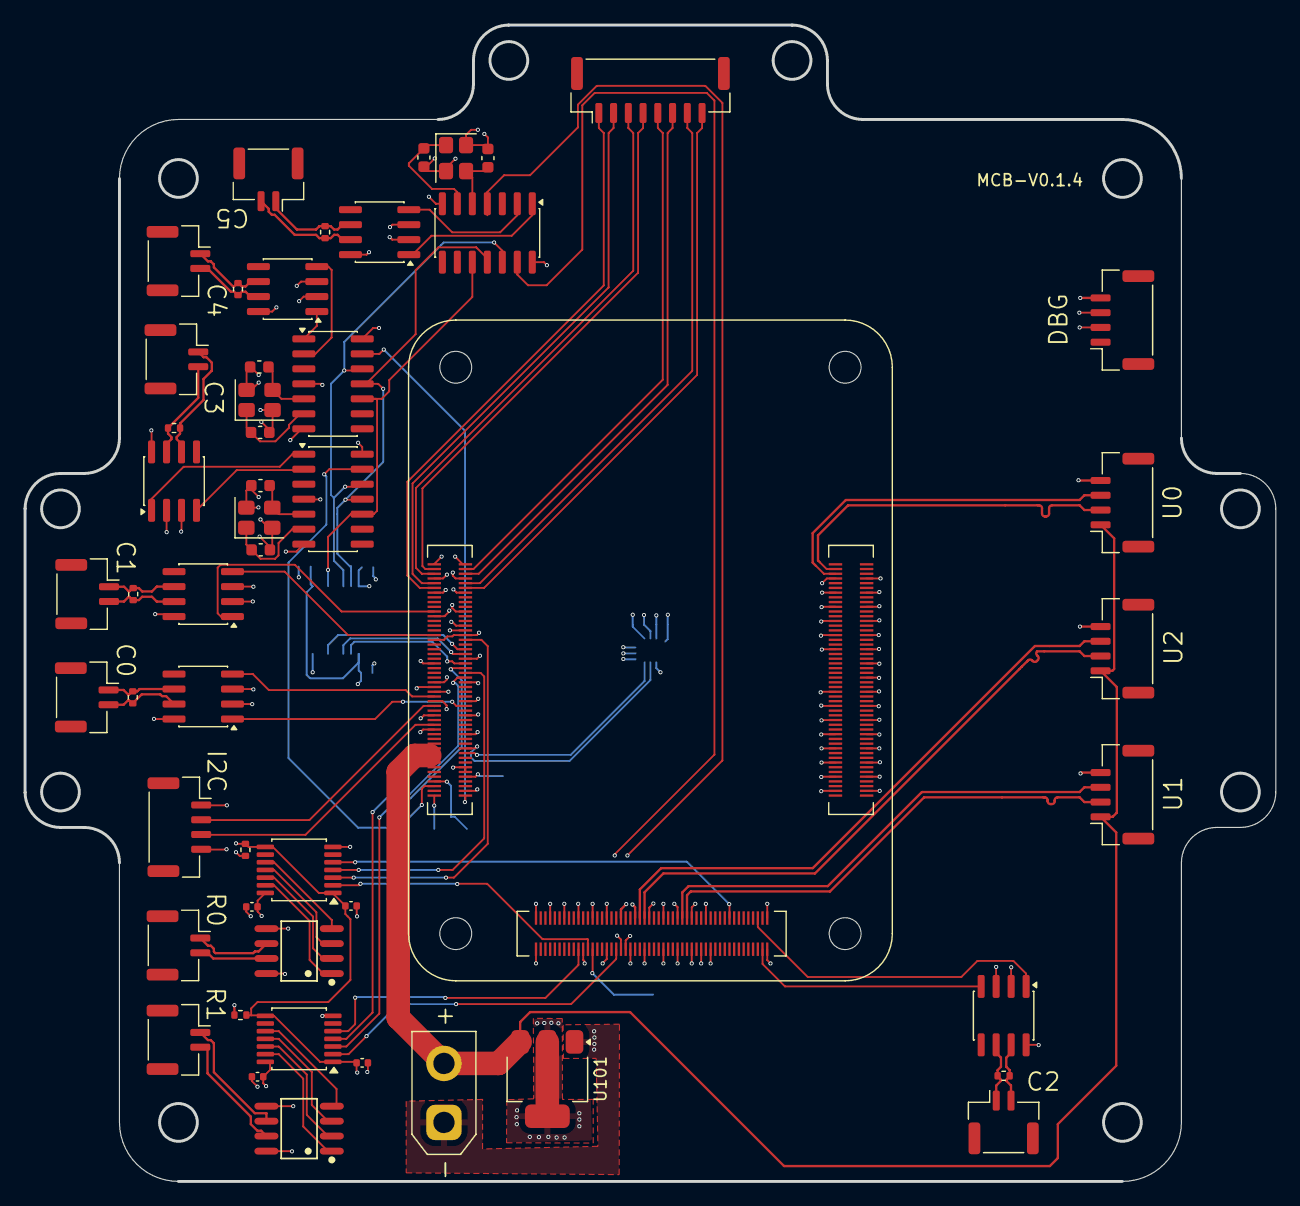
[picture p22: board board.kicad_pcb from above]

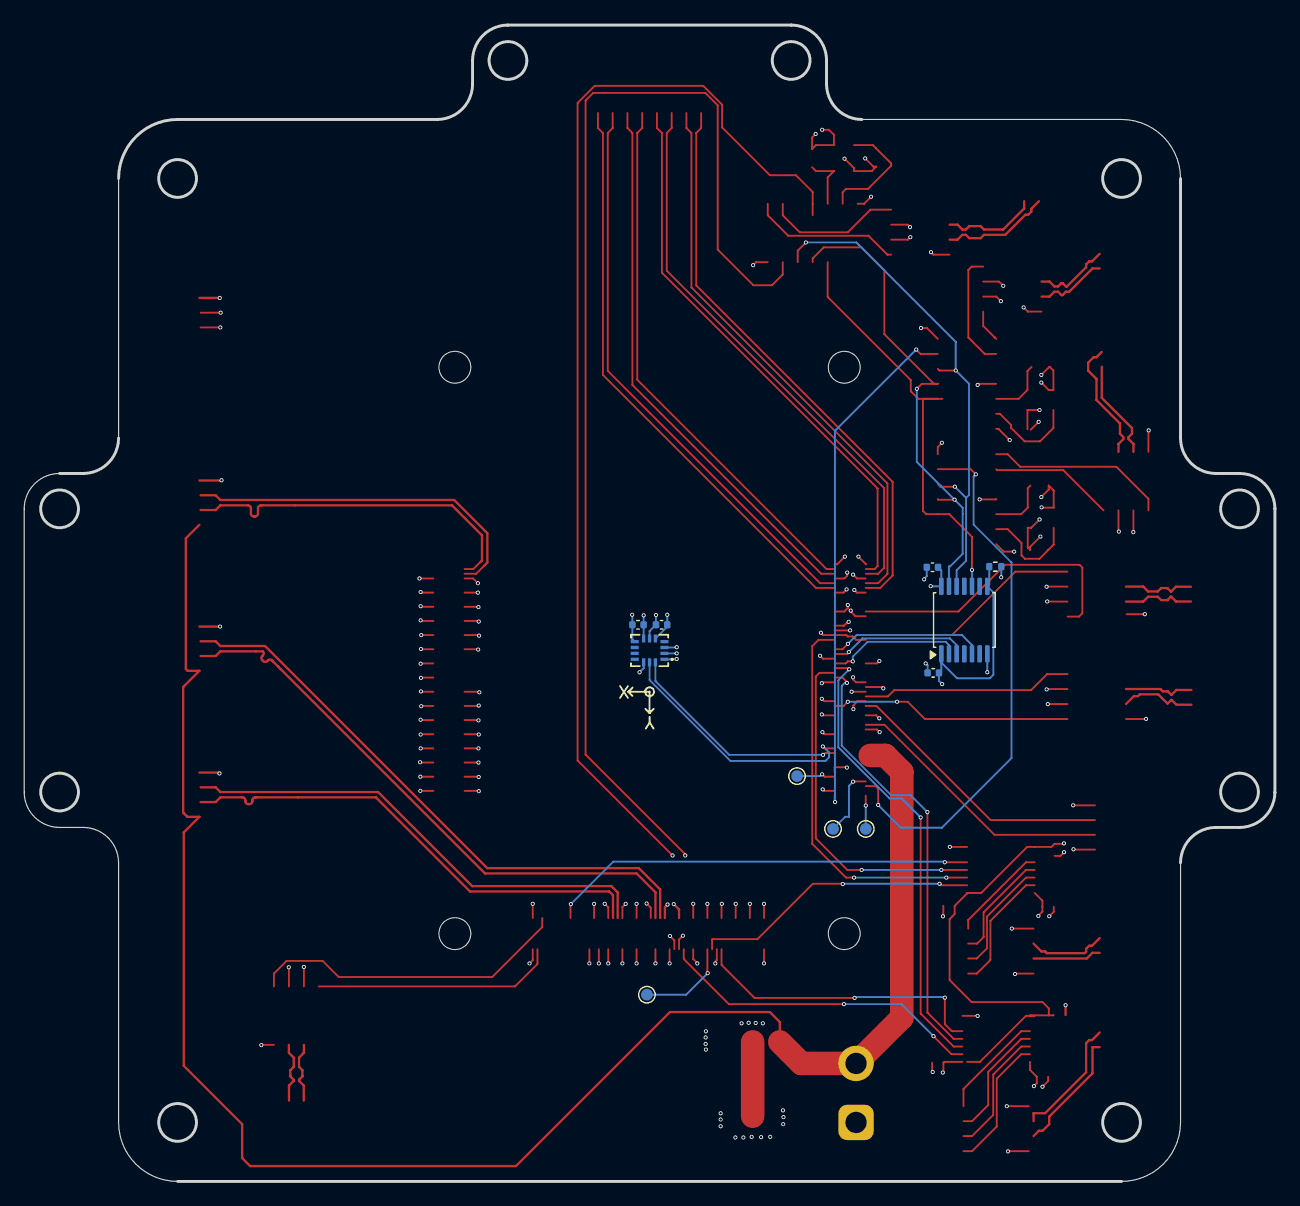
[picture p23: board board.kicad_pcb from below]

Board: 4 copper layers, 106.0 x 98.0 mm, 64 parts (11 on the bottom side), 90 nets.

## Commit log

2026-04-19 Asimov v1 CAD files
    [ASV1_100.STEP, ASV1_100_02A.STEP, ASV1_100_03A.STEP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]
2026-04-20 change the CAD vis url
2026-04-27 Update README with license badge and hardware details
    Updated software license badge and added IMU details for torso and neck DOF for head.
2026-04-30 Adding Motion Control Board v0.1.4 design files (#7)
    [board.kicad_pcb, board.kicad_sch, can.kicad_sch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]
2026-06-21 CATIA import
    CATIA import
    [1600-0515-0006.STEP.STEP_1.STEP.CATPart, 1600-0515-0006.STEP_1.STEP_1.STEP.CATPart, 1600-0515-0006.STEP_1.STEP_2.STEP.CATPart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]

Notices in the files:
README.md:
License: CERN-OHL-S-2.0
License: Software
